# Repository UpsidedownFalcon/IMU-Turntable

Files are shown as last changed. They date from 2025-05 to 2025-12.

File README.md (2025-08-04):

# High-Tech Fidget Spinner: 3-Axis IMU Turntable 

Welcome! 

This is an open-source project for the construction of a 3-DoF IMU turntable, called the "High-Tech Fidget Spinner". It is a low-cost alternative to commercial solutions which can cost in the 5 to 6-figure USD range, to be used for the validation and characterisation of IMU sensors. 

015_Tease2

System Architecture

The repository contains supporting files to the conference paper titled "High-Tech Fidget Spinner: Open-Source 3-Axis Turntable" from UbiComp Companion ’25, October 12–16, 2025, Espoo, Finland: https://doi.org/10.1145/3714394.3756256 

The top-level strucutre of the repository is as follows: 

```
.
├── build/              # 3D-printing files, instructions and BoM to construct the hardware    
├── docs/               # Project development and conference paper documentation 
├── src/                # Code for the webapp and controller firmware    
├── testing/            # Files from testing the High-Tech Fidget Spinner 
├── tools/              # Files to select approrpriate stepper motors 
├── LICENSE.md         
└── README.md           
```

Each directory has its own README file that contains further details about it. 

## Getting started 

0) Familiarise yoursel with the directories in this repository and their README files and the overview paper at https://doi.org/10.1145/3714394.3756256  

1) Construct the hardware as described in [```/build/```](/build/) 

2) Upload the firmware as described in [```/src/```](/src/)

3) Launch the webapp as described in [```/src/```](/src/) 

4) You're ready to use the project! Usage instructions can be found at [```/docs/how-to-use.md```](/docs/how-to-use.md) 

5) Modify as you need for your applications :) 

## Next steps 

The High-Tech Fidget Spinner is a **WORK IN PROGRESS** as of August 3, 2025. The community should follows this repository for the latest iterations. 

- A **FORK** of this repository should be created to modify the project for your bespoke applicaiton. 

- An **ISSUE** should be created to suggest changes / bug fixes for the entire community. 

Everyone is welcome to use, collaborate and iterate on this project!

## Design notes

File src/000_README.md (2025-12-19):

# ```/src/``` 

This directory is where all of the code is found! There is a webapp UI where the user can create bespoke trajectories and save them onto a MicroSD card. Then the MicroSD card can be inserted into the Teensy 4.1-based controller board for the High-Tech Fidget Spinner to execute the bespoke trajectories. This directory contains the code for the Teensy 4.1-based controller board and the webapp. 

```
├── firmware/          # Code for the controller board 
├── webapp /           # Code for the web-based UI
└── README.md 
``` 

## ```/src/firmware/``` 
- [```./main/main.ino```](/src/firmware/main/main.ino) is the code that should be flashed onto the controller board 
- [```./test-scripts/```](/src/firmware/test-scripts/) contains test code snippets 

## ```/src/webapp/``` 
- [```./static/```](/src/webapp/static/) contains CSS and JS files for the webapp 
- [```./templates/index.html```](/src/webapp/templates/index.html) is the HTML file for the webapp 
- [```./webapp.py```](/src/webapp/webapp.py) is the Python backend for the web UI 

## Using the code 

[```/src/firmware/main/main.ino```](/src/firmware/main/main.ino) can be uploaded to the Teensy 4.1 using the Arduino IDE by following the guide on https://www.pjrc.com/teensy/tutorial.html. 

You should run [```/src/webapp/webapp.py```](/src/webapp/webapp.py) to launch the webapp! ```pip install``` can be used to install any libraries that you don't have.

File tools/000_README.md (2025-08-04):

# ```/tools/``` 

There is a large variety of different stepper motors with different operating parameters. An appropriate combination of stepper motors must be chosen, because for example, the base stepper motor will experience the greatest load. This directory contains a model to output appropriate stepper motor combination from the inertia modelling in [/docs/development-log/PRD.md](/docs/development-log/PRD.md).  

```
├── /stepper-selection-model/
|   ├── stepper_data.csv                    # Different stepper motors' operating data 
|   ├── stepper_options.csv                 # Model output containing feasible stepper combinations 
|   └── stepper-selection-model.py          # Python model to choose approrpiate stepper motors 
└── README.md 
```

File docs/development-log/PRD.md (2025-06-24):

Product Requirements Document 
=============================

Contents
=========

1. [Rationale](#1-rationale)
2. [Design Brief](#2-design-brief)
3. [Existing Product Analysis](#3-existing-product-analysis) 
4. [Design Specification ](#4-initial-design-specification)
5. [Initial Design Ideas](#5-initial-design-ideas)
6. [Final Design](#6-final-design)
7. [Manufacturing](#7-manufacturing) 

## 1. Rationale 
Inertial Measurement Units (IMU sensors) widely used in wearable technologies. [Hippos Exoskeleton Incorporated](https://www.hippos.life/) are using IMU sensors in their world's first Smart Adaptive Knee Brace to prevent serious knee injuries such as ACL tears. 

In such applications, there is a demand for high frequency IMU measurements. It is also imperative to validate these high frequency IMU measurements to determine the accuracy of the IMU sensor. There is no consistent and economical method between different researchers to do so, hence why this project exists to fill that gap. 

Inertial Measurement Units (IMUs) are critical to wearable exoskeletons but lack a standardised, low-cost method to validate high-frequency data (500–1 000 Hz+) against a ground truth.

- **Problem statement:** Existing IMU validations rely on optical systems (≤240 Hz, ≈42% joint-angle error) or expensive commercial turntables, making cross-study comparison difficult.

- **Opportunity:** An open-source, 3-axis mechanical jig with rotary-encoder ground truth can deliver <9% error validation at high sampling rate

Please read *Research Proposal.pdf* for a detailed overview. 

## 2. Design Brief 
This project must produce an open-source and economical method to characterise and validate IMU sensor data against a ground truth, which can be applied across different researchers to consistently compare the accuracy of different IMU sensors at different sampling rates. 

The open-source hardware and software platform must:
1. Spin IMUs on a motorised 3 DOF jig at controlled trajectories. 
2. Log synchronous IMU and rotary-encoder data.
3. Compute and report accuracy metrics (RMSE, MAE, drift rates, Allan variance).
4. Be fully documented (CAD, firmware, analysis scripts) so that other labs can reproduce and compare results.

## 3. Existing Product Analysis
| Turntable | Rotation DoF | Rotation Range / ° | Rotation Resolution / ° | Linear DoF | Linear range | Linear Resolution | Cost / £ | Open-Source | Source Link |
|---|---:|---|---|---:|---|---|---|---|---|
| **iMAR iTES-PDT07** | 1 | Continuous (∞) | 0.00153 ° (5.5 arcsec) | 0 | N/A | N/A | On request | No | https://imar-navigation.de/en/product/ites-pdt07 |
| **iMAR iTURN-2D1-HIL** | 2 | Continuous (∞) | 0.00000556 ° (0.02 arcsec) | 0 | N/A | N/A | On request | No | https://imar-navigation.de/en/product/iturn-2 |
| **iMAR iTURN-3S1** | 3 | Continuous (∞) | < 0.0002 ° | 0 | N/A | N/A | On request | No | https://imar-navigation.de/en/product/iturn-3s1 |
| **LIOCREBIF Single-Axis Rate & Position Turntable** | 1 | Continuous (∞) | 0.0001 ° | 0 | N/A | N/A | On request | No | https://www.liocrebif.com/single-axis-rate-and-position-turntable |
| **360° Electric Rotating Photography Turntable (B0756FVW78)** | 1 | Continuous (∞) | ≈ 1 ° (no encoder) | 0 | N/A | N/A | £21 | No | https://www.amazon.co.uk/dp/B0756FVW78 |
| **JAYEGT Motorized Rotating Display Stand, 7.87 in** | 1 | Continuous (∞) | ≈ 0.18 ° (stepper microsteps) | 0 | N/A | N/A | £22 | No | https://www.amazon.co.uk/dp/B07XYZ1234 (approx.) |
| **OpenBuilds Compact Rotary Axis (DIY)** | 1 | Continuous (∞) | 0.05625 ° (1.8°/step with 1/32 microstep) | 0 | N/A | N/A | £160 (~\$200*) | Yes | https://openbuilds.com/builds/compact-rotary-axis-laser-engraver.10204/ |

### Rotational Actuators 
<details> <summary> Expand </summary> 
There are three main types of rotational actuation methods: pneumatic, hydraulic and electric. Pneumatic systems require large volumes of compressed air and hydraulic systems require powerful pumps. Hence, they would not be suitable for such an open-source IMU turntable as pneumatic and hydraulic actuators are difficult and expensive to obtain and control. 

For electric actuation methods (motors), there are several different types: 
- DC Motors 
    - DC Shunt Motor 
    - Separately Excited DC Motor 
    - Series DC Motor 
    - PMDC Motor 
    - Compound Motor 
- AC Motors 
    - Induction Motor 
        - 1 Phase Induction Motor 
        - 3 Phase Induction Motor 
    - Synchronous Motor 
- Special Motors 
    - Stepper Motor 
    - Brushless Motor 
    - Universal Motor 
    - Hysterisis Motor 
    - Reluctance Motor 
    - Linear Motor 

Comparing all of the motors against the design brief and specification: 
| **Motor Type** | **Approx. Angular Resolution** | **Control Method** | **Ease of Open-Source Control** | **Accessibility (Motor & Controller)** | **Notes/Comments** |
|---|---|---|---|---|---|
| **DC Shunt Motor** | • No inherent positional resolution (continuous).<br>• With external encoder: resolution = encoder CPR (e.g. 1000–5000 pulses/rev → 0.36–0.072°). | • Voltage/PWM to armature; field winding current is separately regulated (constant–voltage).<br>• Closed-loop position/velocity requires a separate encoder + PID. | • Moderate: plenty of open-source H-bridge/PWM drivers (e.g. VNH2SP30, L298N), open-source PID libraries (Arduino, Python).<br>• But you must pair with an encoder board and write/modify control firmware. | • DC shunt motors (small-frame) are somewhat uncommon compared to PMDC. You’ll likely end up using a small PMDC + stiff field winding rather than commercial “shunt”-type anyway.<br>• Encoder modules (optical/Hall sensor) are off-the-shelf. | • Without an encoder, you have zero positional resolution—only speed control.<br>• With a good encoder and a well-tuned PID loop, you can get “encoder resolution” (e.g. a 2000 CPR encoder → 2000 steps/rev → 0.18° per step).<br>• But this adds mechanical coupling, cost, and closed-loop complexity. |
| **Separately Excited DC Motor**  | • Same as DC Shunt: continuous. With encoder only. | • Armature PWM/voltage + independent field current supply.<br>• Position/velocity control via separate encoder + PID. | • Moderate: open-source drivers for armature.<br>• You also need to drive field winding (often constant DC). For position, same as above (external encoder + PID). | • Rare to find small (<100 W) commercial “SEDC” motors cheaply.<br>• Encoders sold separately. | • Very similar trade-off as DC Shunt.<br>• Slightly more complex field supply but resolution still comes from encoder. |
| **Series DC Motor** | • Continuous unless you clamp/inject feedback via encoder. With encoder: same as above. | • Armature & field current in series → torque varies with load.<br>• Position/velocity control only via encoder + PID. | • Moderate-Low: series DCs are less common for precise control (more used for high-speed or heavy loads).<br>• Open-source PWM drivers exist, but closed-loop tuning is tricky. | • Series DCs are mostly used in industrial big-frame (e.g. traction).<br>• Not recommended for small precision tabletop setups. | • Not typically chosen for low-speed/high-precision tasks because torque changes nonlinearly with load.<br>• Encoder required for any positional control → same complexity as PMDC. |
| **PMDC Motor** | • Continuous rotation.<br>• With external encoder: depends on encoder (e.g. 1000 CPR yields 0.36°/step). | • PWM/analog voltage on armature.<br>• Closed-loop via encoder + PID. | • Moderate: a huge variety of open-source H-bridge drivers (e.g. L298, BTS7960, Pololu Motor Drivers) and PID libraries.<br>• You still need to attach an encoder (often 6–12 mm optical/line encoder modules). | • Very common: 12 V/24 V hobby-grade PMDC motors, cheap.<br>• Encoders widely available (e.g. 512–4096 CPR).<br>• Controllers: easy to source (Arduino shields, Pololu, etc.). | • Many DIY IMU turntables use a PMDC + high-resolution encoder.<br>• You’ll need to machine or 3D-print a coupling to mount the encoder disc.<br>• Control loop tuning (PID) is doable but adds software complexity vs. open-loop stepper. |
| **Compound Motor** | • Same as other DC: continuous. With encoder: same as above. | • Combination of series & shunt field windings; control as “DC motor + encoder.” | • Moderate: identical to DC motors above, but field structure is more complex. | • Rare—compound DC motors default to larger-frame/industrial sizes. | • Overkill for a small, low-power turntable.<br>• Complexity and cost go up for marginal gain over PMDC. |
| **1 Phase Induction Motor** | • No inherent positional resolution (just speed).<br>• Typically no encoder in standard usage. | • AC supply ± V/f control or VVVF (variable-voltage variable-frequency).<br>• For position: must retrofit encoder + VFD with encoder feedback (closed-loop). | • Low: open-source VFD+firmware exist (e.g. OpenVFD), but complex to set up.<br>• Tuning AC V/f control with encoder feedback is nontrivial. | • Small single-phase induction motors are common (ceiling fans, etc.) but rarely sold as “servo-ready.”<br>• VFDs with encoder inputs are industrial gear. | • Not practical for precision.<br>• Difficult to source a “small” 1 phase induction motor combined with a VFD that can do position-loop. |
| **3 Phase Induction Motor** | • Continuous; needs external encoder for any position control (like 1024 CPR → 0.35°). | • 3-phase inverter (VFD) → V/f open loop or vector control closed loop (with encoder). | • Low: projects like OpenInverter & ODrive support BLDC/AC motors, but setting up sensorless or encoder-based FOC for an IM is advanced.<br>• Requires a multi-kW inverter normally. | • Small 3-phase induction motors (e.g. 0.5–2 kW) are available but need a matching VFD.<br>• Commercial VFDs are expensive and not plug-and-play. | • Overkill power & complexity.<br>• Hard to find a compact open-source solution for 3 phase IM position control at tabletop scales. |
| **Synchronous Motor** | • Continuous; with resolver/encoder you get resolution = sensor CPR (e.g. 1024 CPR). | • Synchronous inverter drive (FOC) with encoder/resolver feedback.<br>• Position loop in the inverter. | • Medium-Low: some open-source ESC projects handle BLDC, but true AC synchronous (e.g. permanent magnet synchronous) with encoder is rarer.<br>• Requires writing/using FOC code. | • Small permanent-magnet synchronous motors (PMSM) exist (same as BLDC stator).<br>• Controllers: ODrive or similar can drive PMSM, but hardware is more expensive than stepper drivers. | • If you treat a PMSM like a BLDC (just use FOC + encoder), resolution is same story as BLDC.<br>• More complexity than a stepper for similar closed-loop accuracy. |
| **Stepper Motor** | • Native step angle: typically 1.8° (200 steps/rev) or 0.9° (400 steps/rev).<br>• Microstepping → up to 1/256 microstep. | • Open-loop step pulses (e.g. STEP/DIR) to driver (A4988, DRV8825, TMC²X).<br>• Closed-loop (optional) with encoder but often not needed if torque is adequate. | • Very High: virtually all major open-source platforms (Arduino, Raspberry Pi, etc.) have libraries for step/direction.<br>• Numerous open hardware drivers (e.g. BigTreeTech, CNC shield, TMC drivers). | • Ubiquitous: NEMA 17, NEMA 23 stepper motors are cheap.<br>• Drivers like A4988 (<\$2) or TMC2209 (<\$10) are open source/hardware friendly. | • Industry standard for DIY turntables, 3D printers, CNC.<br>• No encoder needed unless you want absolute position, since open-loop step is predictable.<br>• If you microstep and drive smoothly, you can achieve <0.05° resolution easily.<br>• Torque tapers at very high microstep frequencies—choose a low RPM application. |
| **Brushless Motor** (BLDC/PMSM) | • No inherent position resolution; requires external encoder/ITR.<br>• With 500 CPR encoder on rotor: 0.72° per count, but FOC interpolation can give ~0.1°. | • 3-phase ESC or driver (with FOC).<br>• With encoder or Hall sensors → closed-loop position.<br>• Without sensor → sensorless control (not recommended for precise stepping). | • Medium: boards like ODrive (open-hardware) or SimpleFOC (STM32) let you do FOC + encoder.<br>• More firmware overhead than a stepper. | • Brushless hobby motors are cheap; need to add a 3-phase inverter board + encoder.<br>• ODrive boards start at ~$100; SimpleFOC shields exist. | • Smooth motion and high-speed capability.<br>• More complex wiring (3 phases + encoder).<br>• Open-source BLDC drivers exist but require learning FOC concepts.<br>• You can tune so that effectively you get sub-degree control, but it’s not as “plug & play” as a stepper. |
| **Universal Motor** | • Continuous; requires an encoder for position resolution only. | • Runs off AC or DC (brush + commutator).<br>• Speed roughly ∝ voltage/load.<br>• Position control → PWM + encoder + PID. | • Low: open-source H-bridge PWM control can run it on DC.<br>• But brushes introduce noise; closed-loop tuning is not common. | • Found in power tools/household; not generally sold by RPM characteristics.<br>• Encoder + coupling required. | • Not used for precision positioning; mostly high-speed tools.<br>• Brush noise, variable torque curve. |
| **Hysteresis Motor** | • Often used in analog timing; continuous.<br>• No built-in position feedback.<br>• With external encoder: same as DC. | • AC drive at rated frequency; torque due to hysteresis; constant speed so good for timers.<br>• Position control only via external encoder + special driver. | • Very Low: rare to find open hardware for hysteresis motor control.<br>• Most commercial units come as “black box” synchronous timers. | • Extremely niche; mostly in lab instrumentation (analytical balances, audio turntables decades ago). | • Very expensive, low-torque.<br>• Rarely sold off-the-shelf for DIY. |
| **Reluctance Motor** | • Continuous.<br>• Position control requires resolver or encoder. | • 3-phase inverter (FOC or reluctance-specific drive).<br>• Position loop in inverter if encoder/resolver present. | • Low: open-source FOC for reluctance motors is uncommon.<br>• You’d basically need a commercial servo drive. | • Rarely sold at small scales.<br>• More used industrially (traction, servo); not easy to source cheap. | • Not a practical choice unless you already have one. |
| **Linear Motor** (not rotary) | • N/A for angular application. | • Typically voice-coil style (for small); linear brushless for larger. | • Low: open-source happens mainly in pick-and-place robotics, but not relevant for a rotary turntable. | • Widely available as linear actuators but useless for rotation. | • You’d have to convert linear → rotary (belt or gear) which adds inaccuracy. |

The most feasible motors to use are **stepper motors** because they: 
- Can rotate to discrete positions which can be sequentially combined to make them follow continuous rotation trajectories very accurately 
- Have a native angular resolution of 1.8° or 0.9° which can be microstepped up to 1/256 => Hence, a maximum achieveable resolution (with 0.9° native resolutio and 1/256 microstep) is **0.0035°** per microstep 

Using stepper motors, an open-source IMU turntable can be designed in [Initial Design Ideas: Stepper Motor Design](#stepper-motor-design). 
</details>

### Specific Stepper Motors 
<details> <summary> Expand </summary>

| Model | NEMA Size | Step Angle (°) | Holding Torque (N·cm) | Dimensions (mm) | Mass (kg) | Rotor Intertia (gcm2) | Datasheet Link |
|---|---|---|---|---|---|---|---|
| **14HR05-0504S** | NEMA 14 (Φ36.5) | 0.9 | 5 | Φ36.5 × 12.5; shaft Φ5×10.5 | 0.06 | 11.00 | [14HR05-0504S.pdf](https://www.oyostepper.com/images/upload/File/14HR05-0504S.pdf) |
| **14HR08-0654S** | NEMA 14 (Φ36) | 0.9 | 8 | Φ36 × 20; shaft Φ5×15.5 | 0.13 | 13.00 | [14HR08-0654S.pdf](https://www.oyostepper.com/images/upload/File/14HR08-0654S.pdf) |
| **14HM08-0504S** | NEMA 14 (35×35) | 0.9 | 5 | 35 × 35 × 20 | ~0.10 | 8.00 | [14HM08-0504S.pdf](https://www.omc-stepperonline.com/download/14HM08-0504S.pdf) |
| **14HM11-0404S** | NEMA 14 (35×35) | 0.9 | 11 | 35 × 35 × 11.5 | 0.12 | 10.00| [14HM11-0404S.pdf](https://www.oyostepper.com/images/upload/File/14HM11-0404S.pdf) |
| **16HM09-1204S** | NEMA 16 (Φ39) | 0.9 | 11 | Φ39 × 24 | 0.10 | 10.00 | [16HM09-1204S.pdf](https://www.omc-stepperonline.com/download/16HM09-1204S.pdf) |
| **16HM10-0604S** | NEMA 16 (Φ39) | 0.9 | 16 | Φ39 × 24 | 0.12 | 11.00 | [16HM10-0604S.pdf](https://www.oyostepper.com/images/upload/File/16HM10-0604S.pdf) |
| **16HM13-0404S** | NEMA 16 (Φ39) | 0.9 | 18 | Φ39 × 28 | 0.18 | 20.00 | [16HM13-0404S.pdf](https://www.oyostepper.com/images/upload/File/16HM13-0404S.pdf) |
| **16HM17-0304S**| NEMA 16 (Φ39) | 0.9 | 25 | Φ39 × 34 | 0.25 | 36.00 | [16HM17-0304S.pdf](https://www.oyostepper.com/images/upload/File/CN-16HM17-0304S.pdf) |
| **17HM08-1204S** | NEMA 17 (42×42) | 0.9 | 11 | 42 × 42 × 20 | 0.15 | 14.00 | [17HM08-1204S.pdf](https://www.oyostepper.com/images/upload/File/17HM08-1204S.pdf) |
| **17HM13-0316D** | NEMA 17 (42×42) | 0.9 | 23 | 42 × 42 × 34 | 0.28 | 38.00 | [17HM13-0316D.pdf](https://www.oyostepper.com/images/upload/File/17HM13-0316D.pdf) |
| **17HM13-0316S** | NEMA 17 (42×42) | 0.9 | 23 | 42 × 42 × 34 | 0.28 | 38.00 | [17HM13-0316S.pdf](https://www.oyostepper.com/images/upload/File/17HM13-0316S.pdf) |
| **17HM15-0406S** | NEMA 17 (42×42) | 0.9 | 26 | 42 × 42 × 39 | 0.28 | 54.00 | [17HM15-0406S.pdf](https://www.oyostepper.com/images/upload/File/17HM15-0406S.pdf) |
| **17HM15-0904S** | NEMA 17 (42×42) | 0.9 | 36 | 42 × 42 × 40 | 0.28 | 54.00 | [17HM15-0904S.pdf](https://www.oyostepper.com/images/upload/File/17HM15-0904S.pdf) |
| **17HM15-1004S** | NEMA 17 (42×42) | 0.9 | 33 | 42 × 42 × 40 | 0.31 | 54.00 | [17HM15-1004S.pdf](https://www.oyostepper.com/images/upload/File/17HM15-1004S.pdf) |
| **17ME15-1504S** | NEMA 17 (42×42) | 0.9 | 30 | 42 × 42 × 38 | 0.28 | - | [17ME15-1504S.pdf](https://www.oyostepper.com/images/upload/File/17ME15-1504S.pdf) |
| **17HM19-0406D** | NEMA 17 (42×42) | 0.9 | 32 | 42 × 42 × 48 | 0.35 | 68.00 | [17HM19-0406D.pdf](https://www.oyostepper.com/images/upload/File/17HM19-0406D.pdf) |
| **17HM19-1684S** | NEMA 17 (42×42) | 0.9 | 44 | 42 × 42 × 47 | 0.35 | 68.00 | [17HM19-1684S.pdf](https://www.oyostepper.com/images/upload/File/17HM19-1684S.pdf) |
| **17HM19-1684D** | NEMA 17 (42×42) | 0.9 | 44 | 42 × 42 × 48 | 0.35 | 68.00 | [17HM19-1684D.pdf](https://www.oyostepper.com/images/upload/File/17HM19-1684D.pdf) |
| **17HM19-2004S** | NEMA 17 (42×42) | 0.9 | 46 | 42 × 42 × 48 | 0.40 | 82.00 | [17HM19-2004S.pdf](https://www.oyostepper.com/images/upload/File/17HM19-2004S.pdf) |
| **17HM19-2004S1**  | NEMA 17 (42×42) | 0.9 | 46 | 42 × 42 × 48 | 0.37 | 68.00 | [17HM19-2004S1.pdf](https://www.oyostepper.com/images/upload/File/17HM19-2004S1.pdf) |
| **23HM22-2804S** | NEMA 23 (57×57) | 0.9 | 115 | 57 × 57 × 56 | 0.70 | 300.00 | [23HM22-2804S.pdf](https://www.oyostepper.com/images/upload/File/23HM22-2804S.pdf) |

Using this data, appropriate stepper motors can be selected for each axis of rotation, shown in [Final Design: Stepper Motor Selection Calculations](#stepper-motor-selection-calculations).

</details>

## 4. Design Specification  
The open-source IMU turntable must: 
1. 3 degrees of rotational freedom 
2. 360° of rotation about all three axes 
3. Rotational resolution of at least 0.05625°
4. **As cheap as possible** 
5. Variable trajectory control of the turntable 
6. IMU sensor datalogging at variable frequencies 
7. Temporal synchronisation of the IMU data and turntable motion 

## 5. Initial Design Ideas 
From *Research Proposal.pdf*, the following selections have been made: 

### IMU Sensors: 
The following IMU sensors were selected due to their variety in sampling frequency specified on their datasheet and due to the support of SPI. 

**SPI will be used** to transfer IMU data to the datalogger as it is the fastest digital communication protocol between I2C and UART. 

| IMU Sensor | Communication Protocol | Sampling Frequency / Hz | Angular Resolution / ° s^{-1} | Bit Depth |
|---|---|---|---|---|
| Analog Devices ADIS16470 | SPI | 5000 | ±2000 | 16 - 32 bit | 
| InvenSense ICM-20602 | SPI and I2C | 1 - 32000 | ±2000 | 16 bit | 
| Bosch BMI088 | SPI and I2C | 2000 | ±2000 | 16 bit |
| Ceva BNO085 | SPI, I2C and UART | 1000 | ±2000 | 16 bit |

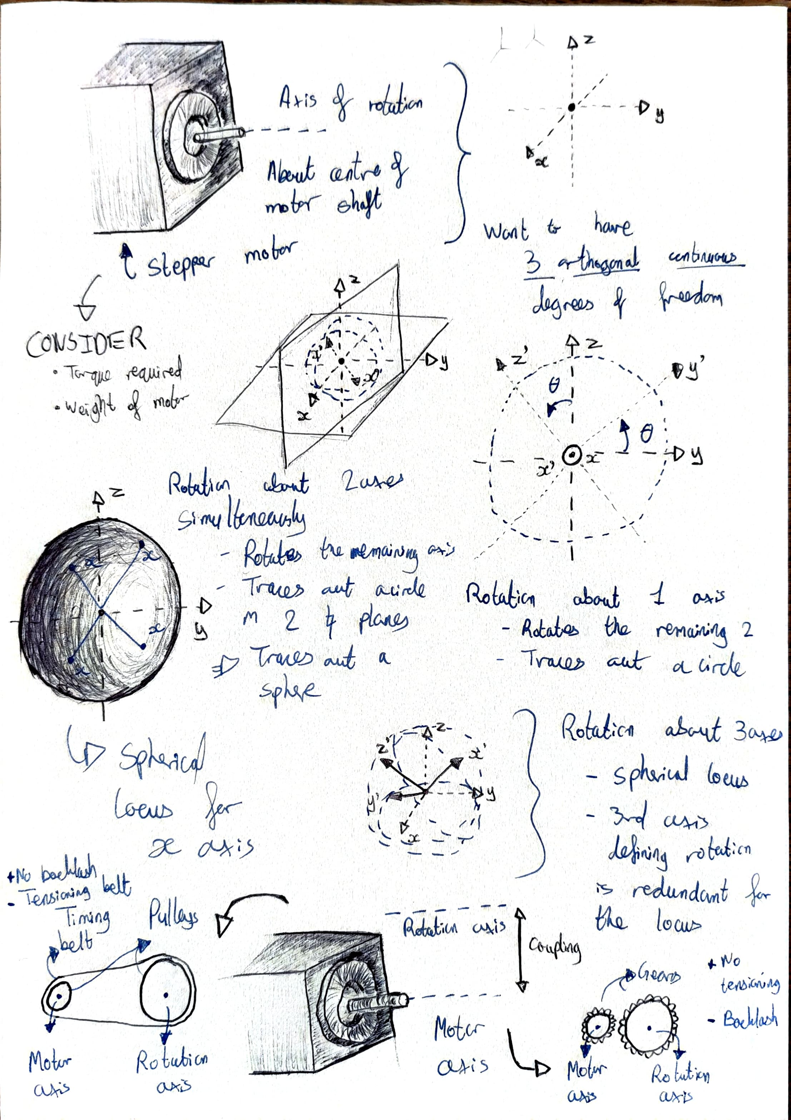
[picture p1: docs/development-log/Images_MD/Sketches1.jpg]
Initial Sketch 1
 
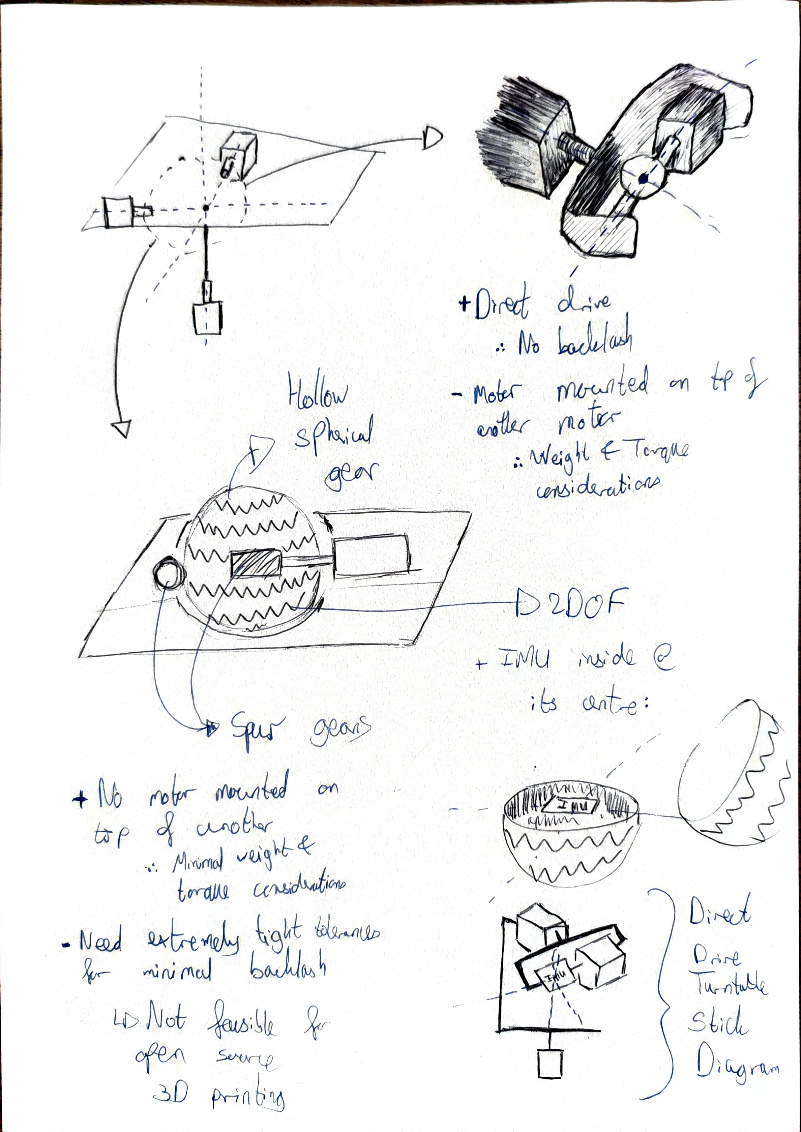
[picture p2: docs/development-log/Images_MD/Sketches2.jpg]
Initial Sketch 2


From the initial design ideas, a direct drive system is the most feasible because *accuracy and precision* are a priority, so **zero backlash** is a necessity. With such a system, the maximum attainable resolution must be further investigated by researching existing rotational actuators e.g stepper motors in [Existing Product Analysis: Rotational Actuators](#rotational-actuators). 

### Stepper Motor Design
<details> <summary> Expand </summary>
Initial design sketch of an open-source IMU turntable actuated using stepper motors: 

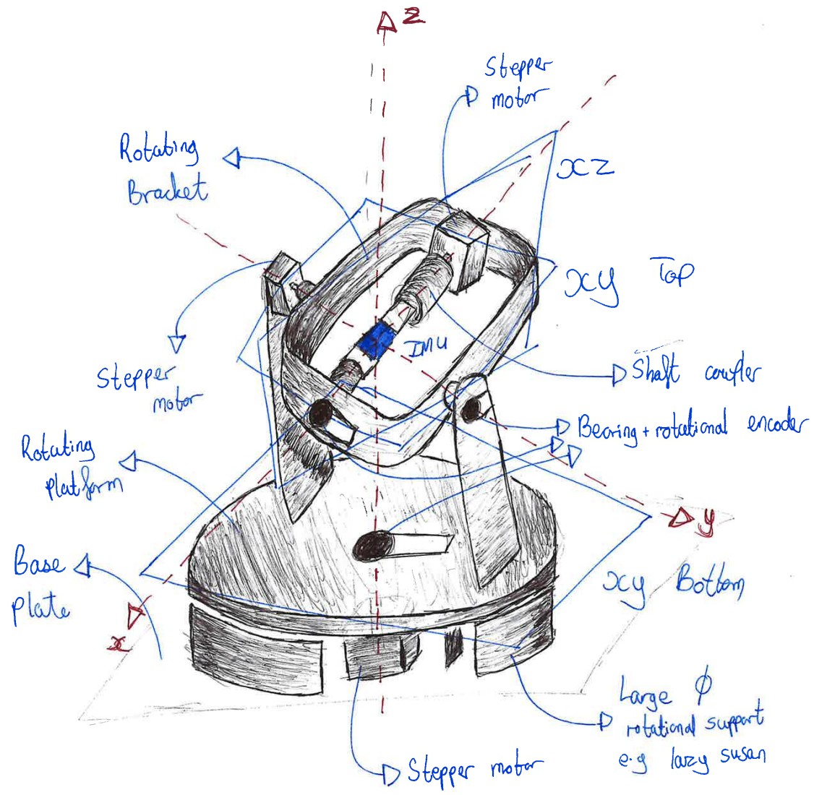
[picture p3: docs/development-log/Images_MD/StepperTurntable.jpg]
Initial Stepper Sketch
 
The drawback with using such a direct drive system is that the stepper motor at the base will have a greater load than the stepper motor at the top because the mass of the turntable + IMU > mass of IMU. **Next step** is to figure out which specific stepper motors to use - for that: 
- Need to research which specific stepper motors there are in [Existing Product Analysis: Specific Stepper Motors](#specific-stepper-motors) and their corresponding torques, dimensions and mass 
- Need to determine which combination of stepper motors to use and where, shown in [Final Design: Stepper Motor Selection Calculations](#stepper-motor-selection-calculations)
</details>

## 6. Final Design 

### Stepper Motor Selection Calculations
<details> <summary> Expand </summary>

- The [Firepower 2TS-450](https://www.accelerometergyro.com/sale-30377756-remote-control-position-rate-turntable-for-ins-imu-test-and-calibration.html) has a maximum angular acceleration of 300 °s^{-2} = **5.236 rads^{-2}**
- **Motor Torque = Load Torque + Friction Torque**, where **Torque = Inertia x Angular Acceleration** 
    - For load torque, **load inertia** depends on the mass and size of the IMU and the frame it's attached to 
    - Friction torque can be modelled as the torque required to spin ANOTHER motor shaft. That's because a bearing + rotary encoder would be used on the other side of the rotating axis. Specific components for the bearing + rotary encoder are yet to be selected, so by modelling them as ANOTHER motor shaft, it gives an OVERESTIMATE to the torque required from the motor. 
- The IMU sensor can be modelled as a solid rod of uniform density by using the maximum mass and dimensions from the list of IMU sensors in the [Initial Design Ideas](#5-initial-design-ideas): 
    - Maximum mass: **11.86g** of the ADIS16470 
    - Maximum length: **15.25mm** of the ADIS16470 

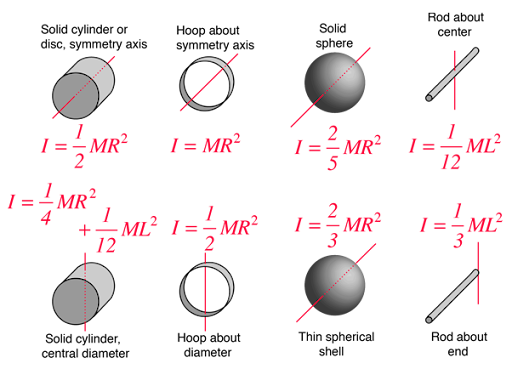
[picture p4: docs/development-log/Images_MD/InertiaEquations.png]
Inertia Equations
 

Hence, **I_IMU** = 1/2 x 11.86E-3 x (15.25E-3)^2 = **1.379E-6 kgm^2**

#### Stage X: Rotation about the X axis 
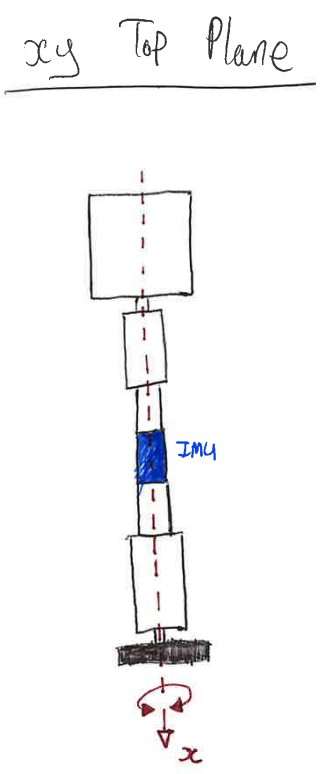
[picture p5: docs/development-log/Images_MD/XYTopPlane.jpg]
Stage X
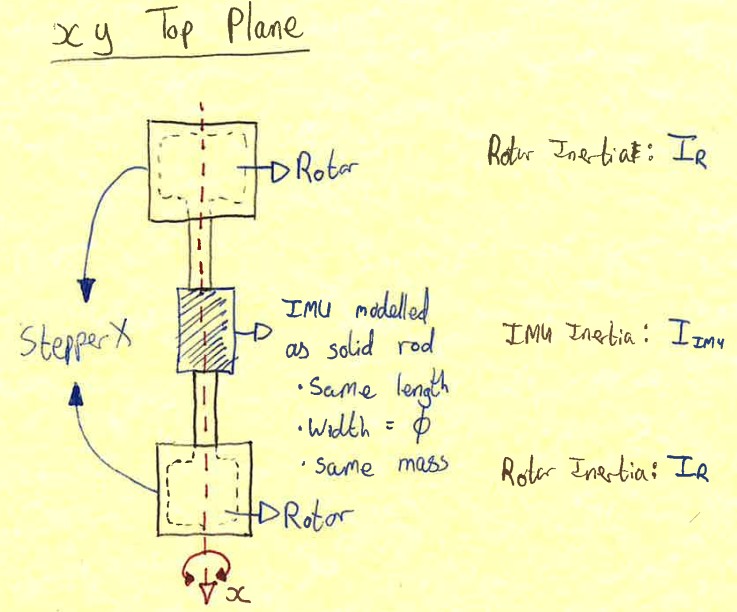
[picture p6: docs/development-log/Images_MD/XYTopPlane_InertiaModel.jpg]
Stage X Inertia Model
 =>  

Since a parts list hasn't been finalised yet, the following modelling assumptions are made to approximate the inertia: 
- Rotor inertia of the stepper motor causes a greater resistance to rotation than the friction in a ball bearing as the rotor has a greater mass than just a rotational axis. Hence, by modelling the resistance to motion due to a ball bearing as the inertia of a rotor will provide an overestimate. 
- Hence, total inertia the motor has to rotate = X Rotor Inertia (I_RX) + IMU Inertia (1.379E-6) + X Rotor Inertia (I_RX)

**=> X Motor Torque = (2I_RX + 1.379E-6)kgm^2 (5.236)rads^{-2}**

#### Stage Y: Rotation about the Y axis 
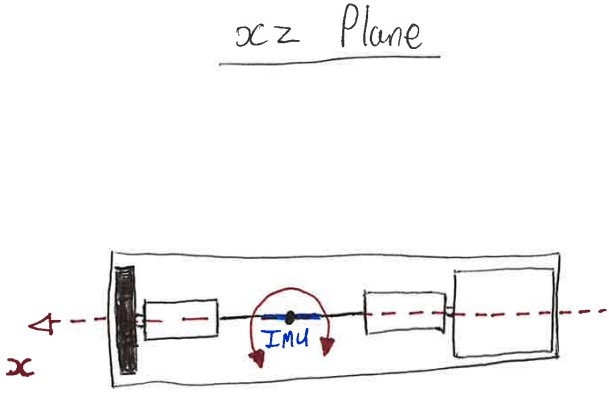
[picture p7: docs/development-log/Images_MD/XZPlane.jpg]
Stage Y
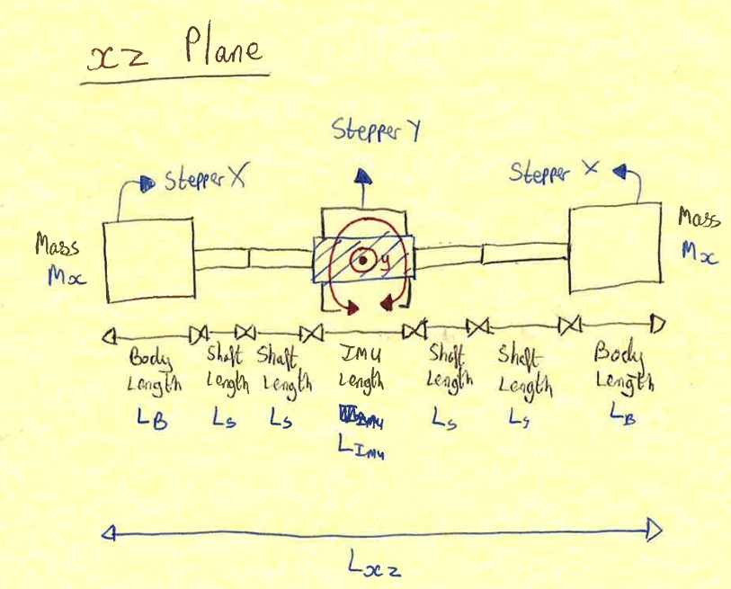
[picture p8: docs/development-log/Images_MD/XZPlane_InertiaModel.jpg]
Stage Y Inertia Model
 => 

Since a parts list hasn't been finalised yet, the following modelling assumptions are made to approximate the inertia: 
- Modelled as a solid rod rotating about its centre normal to its curved surface  
- Mass of rod approx. = (Mass of 2 X stepper motors) + IMU mass 
- Length of rod = 2LB_X + 4LS_X + L_IMU 
- Hence, total inertia by modelling the bearing support to have the same inertia as the Y motor = [1/12 x (2M_X + 11.86E-3) x (2LB_X + 4LS_X + 15.25E-3)^2] + 2 Rotor Inertia (2 I_RY) 

**=> Y Motor Torque = (1/12 (2M_X + 11.86E-3) (2LB_X + 4LS_X + 15.25E-3)^2 + 2 I_RY)kgm^2 (5.236)rads^{-2}**

#### Stage Z: Rotation about the Z axis 
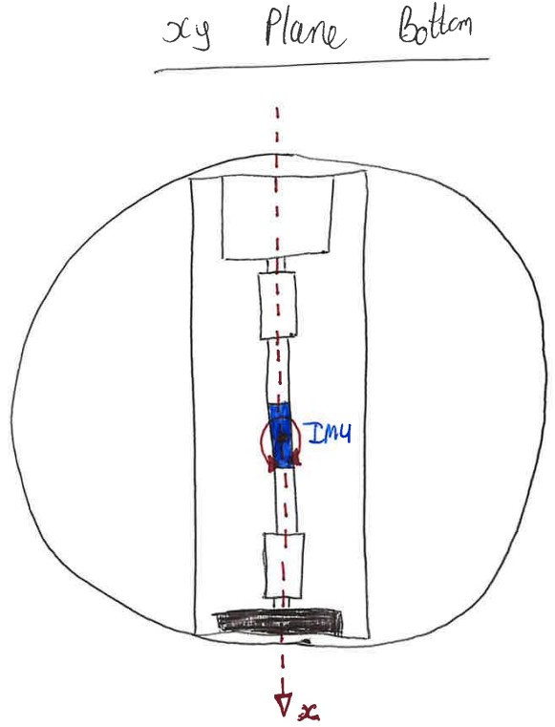
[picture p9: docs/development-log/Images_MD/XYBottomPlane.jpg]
Stage Z
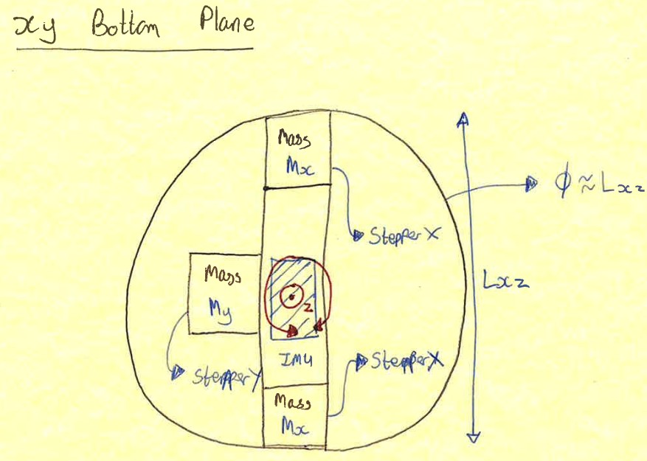
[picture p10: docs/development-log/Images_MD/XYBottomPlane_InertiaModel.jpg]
Stage Z Inertia Model
 => 

Since a parts list hasn't been finalised yet, the following modelling assumptions are made to approximate the inertia: 
- Modelling the rotating platform as an uniform-density rod rotating about its centre that is normal to its face 
- Mass of platform approx. = 2M_X + 2M_Y + M_IMU (assuming mass of Y axis support = M_Y)
- Radius of platform approx. = 1/2 L_XZ = 1/2 (2LB_X + 4LS_X + L_IMU) 
- Total inertia (assuming platform support has same inertia as Z Rotor Inertia) = 1/2 (2M_X + 2M_Y + 11.86E-3) (1/2 (2LB_X + 4LS_X + L_IMU))^2 + 2 I_RZ 

**=> Z Motor Torque = (1/8 (2 M_X + 2 M_Y + 11.86E-3) (2 LB_X + 4 LS_X + 15.25E-3)^2 + 2 I_RZ)kgm^2 (5.236)rads^{-2}**

#### Modelling Different Combinations of Stepper Motors 
As a safety factor, stepper motors will be selected with **at least 10x** the torque than the calculated required torque. 

The variables required are as follows: 
- I_RX: X Rotor Inertia in kgm^2 
- M_X: X Stepper Motor Mass in kg 
- LB_X: X Stepper Motor Body Length in m 
- LS_X: X Stepper Motor Shaft Length in m
- I_RY: Y Rotor Intertia in kgm^2 
- M_Y: Y Stepper Motor Mass in kg 
- I_RZ: Z Stepper Motor Rotor Inertia in kgm^2 

The constants used are as follows: 
- Maximum IMU Mass: 11.86E-3 kg
- Maximum IMU Length: 15.25E-3 m 
- Angular acceleration: 5.236 rads^{-2}

A [Python Script](Stepper_Selection_Model/Stepper_Selection_Model.py) was written to produce a list of [possible stepper motor combinations](Stepper_Selection_Model/stepper_options.csv). The following stepper motors are selected in row **1389**: 
- **X Axis Stepper Motor:** 14HM11-0404S 
- **Y Axis Stepper Motor:** 16HM17-0304S
- **Z Axis Stepper Motor:** 17HM19-2004S1
These motors can be purchased from [Stepper Online](https://www.omc-stepperonline.com/). 

Due to lead time of components from specialist electronic suppliers, the stepper motors were bought from Amazon instead. The desired models weren't available so the following were bought: 
- Nema 17 42-23 
- Nema 17 42-38 
- Nema 17 42-60 

[Rotary Encoder, Magnetic, Incremental, 4096 CPR, Straight](https://uk.farnell.com/broadcom/aeat-901b-r06/magnetic-encoder-incremental-straight/dp/4568216) were ordered due to lead time from Farnell. 

</details>

Largest IMU length was 33.25mm. Want to make an IMU mounting cradle where any IMU can be mounted and adjusted such that the IMU SoC is about the centre of the axes. Hence, cradle lengths should be double that @ ~70mm. 

## 7. Manufacturing

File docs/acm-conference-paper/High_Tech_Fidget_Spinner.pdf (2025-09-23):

# High-Tech Fidget Spinner: Open-Source 3-Axis Turntable

## Bhavy Vaibhav Metakar (https://orcid.org/0009-0001-6696-5230)

Hippos Exoskeleton Incorporated
London, United Kingdom
University College London
Electronic and Electrical Engineering London, United Kingdom
zceebme@ucl.ac.uk

## Thomas J. Gilbert (https://orcid.org/0000-0002-8846-8593)

University College London
Electronic and Electrical Engineering London, United Kingdom
thomas.j.gilbert@ucl.ac.uk

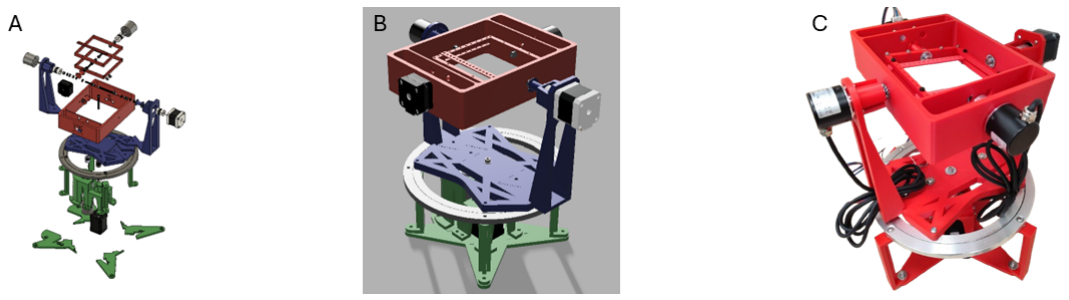
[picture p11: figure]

Figure 1: 3-DoF IMU-turntable exploded view (A), rendered model (B) and working prototype (C).

## Abstract

This paper presents an unprecedented fully open-source, 3-DoF turntable designed to enable precise characterisation and validation of inertial measurement units (IMUs), for under £500, which is a fraction of the cost of commercial systems. This design combines 3D-printed mechanical parts, off-the-shelf 3D printer electronics, and custom firmware with a web-based trajectory generator. Users define piecewise motion profiles for roll, pitch, and yaw via a cross-platform GUI; trajectories are saved to microSD and executed on a Teensy 4.1-based controller. The system can achieve a mean deviation as small as 0.0277◦ with a resolution of up to 0.0457◦
, and can hold a wide range of different IMU devices within a 100 mm × 100 mm area using its universal mounting fixture. All CAD files (STL/3MF/Fusion 360), electronics schematics, firmware source code, and configuration tools are freely available under the GNU GPLv3 licence. This platform lowers the barrier to rigorous IMU testing for researchers, educators, and makers without six-figure budgets, which is the cost of commercial solutions.

## CCS Concepts

- Hardware → Semi-formal verification; PCB design and layout.

## Keywords

3D Design, Custom Firmware, IMU, Testing, CAD, PCB Design, web app UI, Open-Source, FAIR

This work is licensed under a Creative Commons Attribution-NonCommercial 4.0 International License. (https://creativecommons.org/licenses/by-nc/4.0)
UbiComp Companion ’25, Espoo, Finland
© 2025 Copyright held by the owner/author(s).
ACM ISBN 979-8-4007-1477-1/2025/10 https://doi.org/10.1145/3714394.3756256

ACM Reference Format:
Bhavy Vaibhav Metakar and Thomas J. Gilbert. 2025. High-Tech Fidget Spinner: Open-Source 3-Axis Turntable. In Companion of the 2025 ACM International Joint Conference on Pervasive and Ubiquitous Computing (Ubi-Comp Companion ’25), October 12–16, 2025, Espoo, Finland. ACM, New York, NY, USA, 7 pages. https://doi.org/10.1145/3714394.3756256

## 1 Introduction

Wearable motion tracking systems increasingly rely on inertial measurement units (IMU sensors) to capture biomechanical kinematics live in the field, outside of laboratory settings. As such, IMU sensors are described as a cost-effective alternative to laboratory gold standards [1]. The total addressable market (TAM) for wearables grew by 23.1% from 2020 to 2021, reaching $10.28 billion [21], with 84% of devices used for exploring upper extremity musculoskeletal conditions containing IMU sensors [34].
Conventional IMU validation against optical motion capture systems is prone to marker misalignment, frame rate limitations, and soft tissue artefact (STA) in biomechanical contexts [23], producing a reported error of up to ±42◦ using a VR-based system [33]. Mechanical rigs with rotary encoders (turntables) offer a more accurate ground truth with a relative error below 9% [19]. Such IMU turntables are commercially available, but they are costly in the 5 to 6-figure USD range with proprietary firmware as shown in Table 1. This causes inconsistent data comparisons across different studies, and high costs hinder reproducible research.

## 1.1 Contributions

To address the aforementioned challenges, this paper presents the “High-Tech Fidget Spinner" (the artefact). It is a fully documented, vendor-agnostic and low-cost open-source turntable for IMU characterisation and data validation. This project contributes:

UbiComp Companion ’25, October 12–16, 2025, Espoo, Finland | Bhavy Vaibhav Metakar and Thomas J. Gilbert
- Hardware and Mechanical Design: A modular 3-DoF gimbal, built from 3D-printed PLA and standard 3D printer parts,
that executes preset trajectories and universally mounts any IMU device within a 100 mm × 100 mm frame.
- Electronics and Control: A control system based on a Teensy 4.1 microcontroller with three TMC2209 drivers and rotary encoders to execute a preset trajectory and capture the ground truth.
- Firmware and Software: Custom C++ firmware reads binary trajectory files from a microSD card, and a Python web app enables intuitive generation of piecewise X/Y/Z profiles.
- Open Ecosystem: Full CAD files, BOM, schematics, source code, and documentation released under the GNU GPLv3 licence.
- Validated performance: Customisable and repeatable rotations about 3 axes with sub-degree precision.

## 2 Related Work

This section outlines existing commercial closed-source, open-source IMU validation turntables and open-source principles.

## 2.1 Commercial IMU Validation Rigs

Table 1 shows different DoF, resolution and sample rate specifications for commercial turntables; prices are usually omitted, though the 3LT400 and 1LT300 retail in the six-figure USD range. Except for the JAYEGT turntable, they offer at least ≈ 0.001◦
angular resolution and sampling rates from 100 Hz − 1000 Hz.
The JAYEGT turntable is a novelty item, often used for photography. It is not designed to calibrate IMU sensors. Although such a device has a minimal cost barrier, it is not suitable for IMU calibration; its resolution data and sample rate, amongst other things, are not available.

## 2.2 DIY and Academic IMU Validation Rigs

There are free plans available on the internet for DIY 1-DoF turntable builds [13, 25, 30], as well as the construction of a simple turntable from an academic project [32].
Some designs available online employ 3D-printed gear mechanisms [13, 25]. Such mechanisms are not suitable for a turntable designed to characterise and validate IMU data due to the non-zero backlash [7].
Other designs [30, 32] employ a direct connection between the rotational actuator shaft and turntable. Two rigidly-coupled rotating shafts eliminate the issue of backlash, but the designs omit rotary encoders for IMU ground truth measurement.

## 2.3 Open-Source Hardware in Wearables

Open-source hardware should be findable, accessible, interoperable and reproducible [2]. With commercial solutions, they are findable but not accessible due to their cost, not interoperable due to their proprietary firmware and not reproducible due to companies’ intellectual property rights. DIY solutions are often findable, accessible, interoperable with modifications and reproducible, but they are not fit for IMU characterisation and validation.

Table 1: Comparison of commercial IMU turntables

Model | Cost / USD | DoF | Resolution / ° | Sample Rate / Hz
Firepower Control 3LT400 [28] | 210, 000.00 | 3 | 0.000833 | 80

Firepower
Control
2TS-450 [5]
NA | 2 | 0.006 | 1000

Blue Equator
BE-INS2-
22D08 [10]
NA | 2 | 0.00139 | NA

Firepower
Control
1LT300 [29]
180, 000.00 | 1 | 0.0001 | 100

iMAR iTES-PDT07 [16]

NA | 1 | 0.00153 | NA

iMAR
iTURN-2D1-
HIL [15]
NA | 2 | 5.56 × 10⁻⁶ | 1000

iMAR
iTURN-3S1
[14]
NA | 3 | 0.0002 | 1000

JAYEGT
Motorized
Rotating Display Stand
[18]
41.90 | 1 | NA | NA

## 3 Artefact Overview

This section outlines the design goals for the artefact, the rationale for choosing them and a high-level overview of the system.

## 3.1 Design Goals

From studying the Related Work, the following design goals were chosen to fill in the gaps identified:

- 3-DoF to outperform some commercial options.
- Synchronous logging of IMU and ground truth data.
- Fully documented and low-cost to be FAIR-compliant [2].
- 360◦ of continuous rotation about all of its axes, to match commercial solutions in Table 1.
- A rotational resolution ≤ 0.05625◦
to surpass the maximum
resolution of another stepper-motor-based turntable [32].
- Bespoke user-defined trajectories for versatility.

## 3.2 System Architecture

A browser GUI (HTML/CSS/JS frontend, Python/Flask backend) lets users define bespoke piecewise motion profiles and stepper motor parameters. It discretises each axis’s trajectory into timed angle steps, saves them to a microSD card, and the Teensy 4.1 controller (with TMC2209 drivers) loads and executes them on the X, Y, and Z stepper motors. During operation, the controller logs the ground

High-Tech Fidget Spinner: Open-Source 3-Axis Turntable | UbiComp Companion ’25, October 12–16, 2025, Espoo, Finland

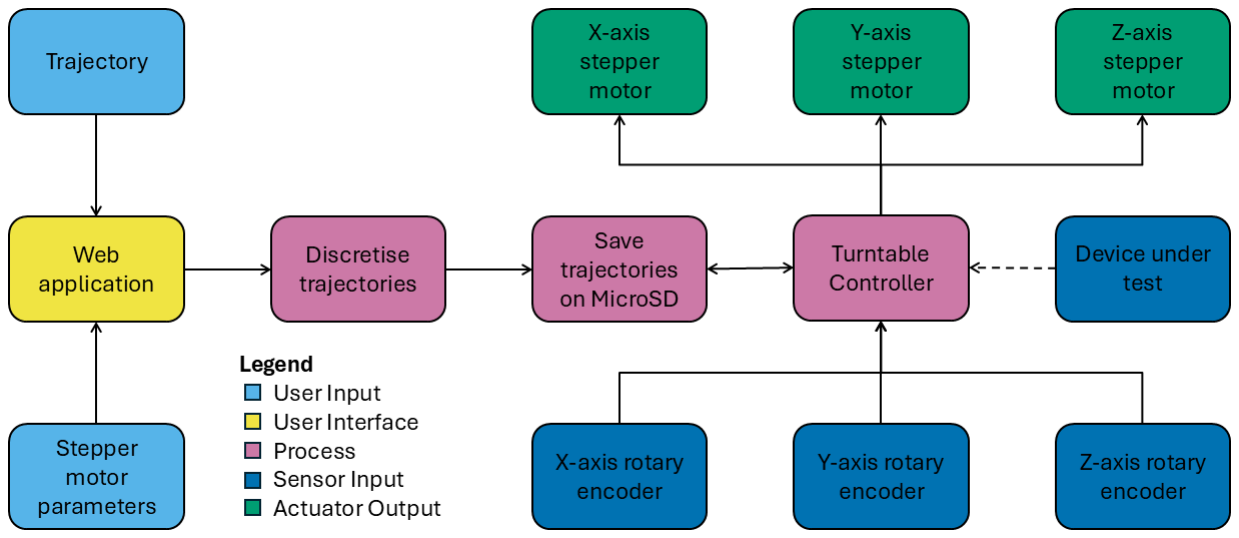
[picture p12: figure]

Figure 2: Browser GUI exports users’ trajectories as binary files to microSD, which the artefact executes.

truth via rotary encoders, and IMU data can stream over UART, I2C, or SPI, or be logged separately.

## 4 Mechanical Design

The artefact consists of a 3-DoF gimbal structure with motor and sensor mounts. The base rotates about the Z-axis. On top of the base, two orthogonal rotating gantries are mounted to rotate about the X and Y axes. A rigid shaft coupling was chosen between the stepper motors and rotating bodies over gearboxes or pulleys to eliminate backlash [7]. Various ball bearings support each frame, constrain a frame’s rotation to only its own axis and maintain orthogonal axes. All rotational frames and brackets were printed in PLA on a Bambulab X1E (0.2 mm layer height, 15 % infill), and the universal fixture clamps in 85A TPU on an Ender 5 (0.2 mm layer height, 20 % infill). Two different 3D printers were used to print the PLA and TPU parts in parallel, as printing in TPU requires a slower print speed and hotter nozzle temperature than PLA [3].
PLA offers higher stiffness (Young’s and bending moduli) and impact strength than ABS or PETG. PLA has minimal warp and does not need a heated bed or enclosure, unlike ABS or PETG [22]. Its low glass transition (≈ 60 ◦C [22]) limits use to below that temperature but ensures superior rigidity and dimensional stability in that range. PLA prints without enclosures or filtration systems, making it broadly accessible.

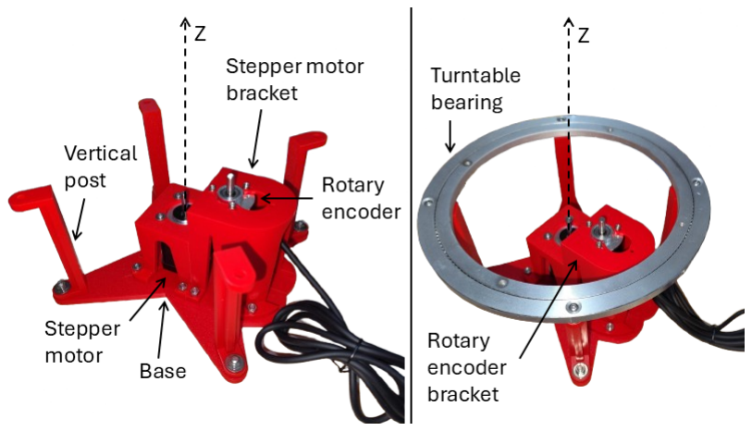
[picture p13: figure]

Figure 3: Base frame subassembly (left) for rotation about the Z-axis. A turntable bearing (right) adds stability to the subassemblies mounted on the base.

Figure 3 (left) shows the base subassembly with 4 vertical posts; a bracket for the base stepper motor; a bracket for the base rotary encoder, and a turntable bearing (right). The bearing mounts on top of the vertical posts to constrain undesired motion [11] for subassemblies on top of the base. The base stepper motor rotates the device under test (DUT) about the Z-axis, and the base rotary encoder measures the rotation about the Z-axis. The rotary encoder is connected to the stepper motor via a GT2 timing belt due to their minimal backlash, as the “backlash is distributed over a full half turn rather than happening immediately on direction change" [27]. Due to practical design considerations of a direct connection between the Z-axis rotary encoder and rotating subassemblies on top of the base, the rotary encoder was driven by a timing belt and pulley system rather than a direct-drive system.

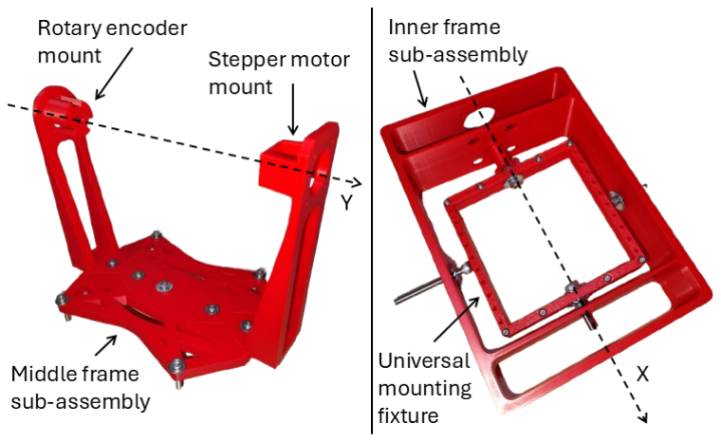
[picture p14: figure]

Figure 4: Middle frame subassembly (left) and inner frame subassembly (right) with rotational axes drawn.

Figure 4 (left) shows the middle subassembly with a mount to the turntable bearing on the base; a stepper motor mount, and a rotary encoder mount. It can be mounted to the turntable bearing on the base to ensure stable rotation in the X-Y plane, and a stepper motor and rotary encoder can be mounted along the Y-axis. This allows for rotation about the Y-axis and its measurement.
Figure 4 (right) shows the inner subassembly with a mount for the DUT; a stepper motor mount; a rotary encoder mount, and a mount to the middle assembly. The mount to the middle assembly is a pair of M5 machine screws which attach to the Y-axis stepper motor and rotary encoder through a set of bearings. The inner assembly can be connected to a stepper motor and rotary encoder to rotate the DUT about the X-axis and measure its rotation. The mount for the DUT forms part of the universal mounting fixture, with its other part being 3D-printed out of TPU.
Figure 1C shows the complete mechanical assembly of the artefact with a single point of rotation in the middle of the inner frame about three orthogonal axes. Its cost is under £500 (≈ $670).

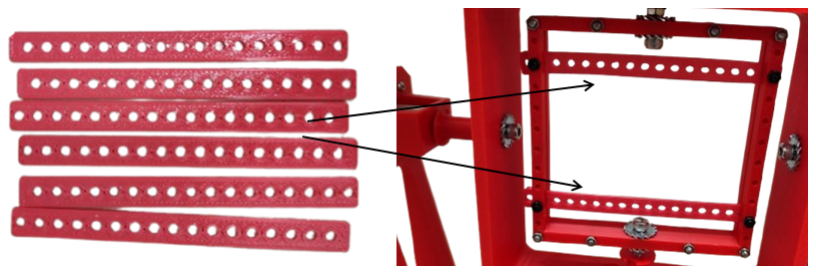
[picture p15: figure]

Figure 5: Universal mounting fixture made out of TPU (left) attached to the inner frame (right).

Figure 5 shows the second half of the universal mounting fixture which is 3D-printed out of TPU and attached to the inner frame.

The user can configure how many TPU mounts they need, where to place them and their tension using the holes in the TPU mount and the inner frame. The TPU mount is attached to the inner frame using M3 machine screws.

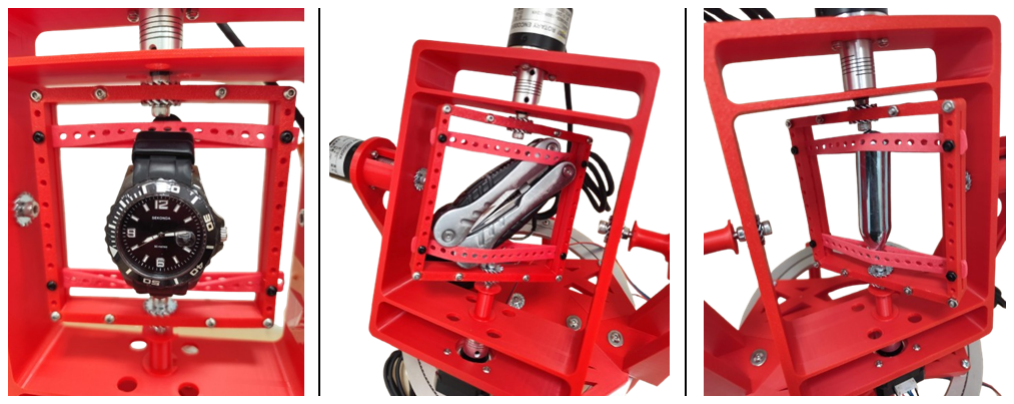
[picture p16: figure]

Figure 6: A watch (left), a multitool (middle) and a CO2 canister (right) secured using the universal mounting fixture.

Figure 6 shows the universal mounting fixture securely holding a watch, a multitool and a CO2 canister to demonstrate that it can hold a range of different objects, and hence, a range of IMU devices. The user has flexibility over where and how to place their object for their bespoke application.

## 5 Electronics and Firmware

This section describes the rationale behind the electronic components chosen, shows the schematic and gives an overview of the web app UI.

## 5.1 Stepper Motor Selection

5.1.1 Stepper Motors. To achieve 360◦

rotation and ≤ 0.05625◦
resolution on the 3-DoF IMU turntable, open-loop stepper motors were selected for their high native angular precision, simple control and availability [6]. Standard 1.8
- or 0.9

◦
stepper motors (200 or
400 steps per revolution), with up to 1 256 microstepping, provide a maximum of 0.0035◦
resolution per microstep [4]. Drivers that accept step and direction inputs obviate the complexity of feedback control required for DC or BLDC motors [31].

5.1.2 Dynamic Torque Modelling. Firepower Control’s 2TS-450 IMU turntable has an angular acceleration of 300 ◦
s

−2
[5]. To match
that lowest commercial angular acceleration from Table 1, each axis was modelled as a compound rigid body composed of cumulative frame, rotor and payload inertias. The model can be found in ./docs/development-log/PRD.md [26]:
- X-axis: τ = (2IRX + IIMU) · α
- Y-axis: τ =
1
12 (2MX + MIMU)L

2 + 2IRY
- α
- Z-axis: τ =
1
2

(2MX + 2MY + MIMU)R

2 + 2IRZ
- α

5.1.3 Selected Motors. A Python script in ./tools/stepper-selectionmodel/stepper-selection-model.py [26] was used to select appropriate stepper motors, filtering for those that meet the required torque, size, and inertia constraints with adequate margin and lead time:

- X-axis: Nema 17 42-23
- Y-axis: Nema 17 42-38
- Z-axis: Nema 17 42-60

5.1.4 Microcontroller, Drivers and Rotary Encoders. To maximise versatility, the controller is required to accommodate a user-supplied IMU and allow firmware extension to log data over any digital communication protocol. Commercial IMU turntables in Table 1 employ heterogeneous interfaces (such as CAN bus, which data loggers like laptops lack, and non-uniform USB ports/protocols), and data loggers support varied standards, including CAN bus, SDI-12, and MODBUS. Given the absence of a single, universal logging standard [12], reliance on any one would compromise interoperability; hence, the system must operate autonomously, necessitating onboard storage for recorded data.
Dynamic current control ensures smooth stepper motor performance under varying loads, and support for up to 256 microsteps maximises angular resolution and functional flexibility.
Optical rotary encoders were chosen over magnetic alternatives due to their superior accuracy and resolution [24].
The following components were chosen for the artefact’s controller due to their technical specification, cost and lead time:
- Microcontroller: Teensy 4.1 due to its 42 assignable GPIOs for UART, I2C and SPI, and a built-in microSD card slot [17].
- Stepper motor driver: TMC2209 due to its SpreadCycle chopper dynamic current control and 256 microstepping resolution [31].
- Rotary encoder: E38S6G5-600B-G24N optical rotary encoder, with 2400 quadrature pulses per revolution (PPR) [8].

## 5.2 Schematic

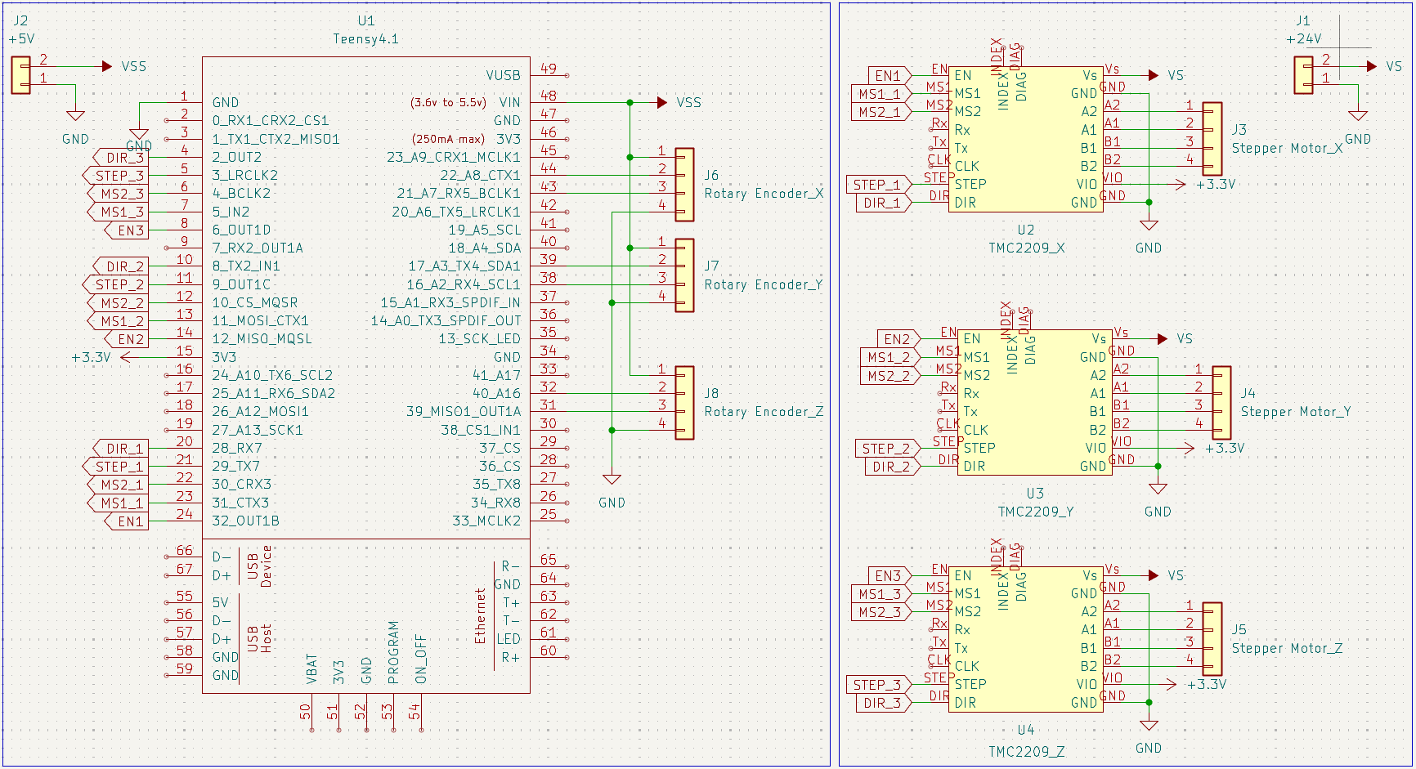
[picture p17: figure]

Figure 7: Schematic of the controller for the artefact.

Figure 7 shows the controller schematic consisting of a Teensy 4.1 microcontroller, three TMC2209 drivers, header pin connectors to the stepper motors and rotary encoders. It can be found in ./build/PCB/kicad [26] and can be constructed on a breadboard with an external power supply (≥ 120 W) for +24 V and +5 V. Files are also provided to manufacture a PCB.

## 5.3 Code Explanation

The web app GUI shown in Figure 8 allows the user to adjust stepper motor parameters; enter a piecewise trajectory for each axis; display the entered trajectory and discretise the trajectory to be saved onto a microSD card for execution by the artefact.

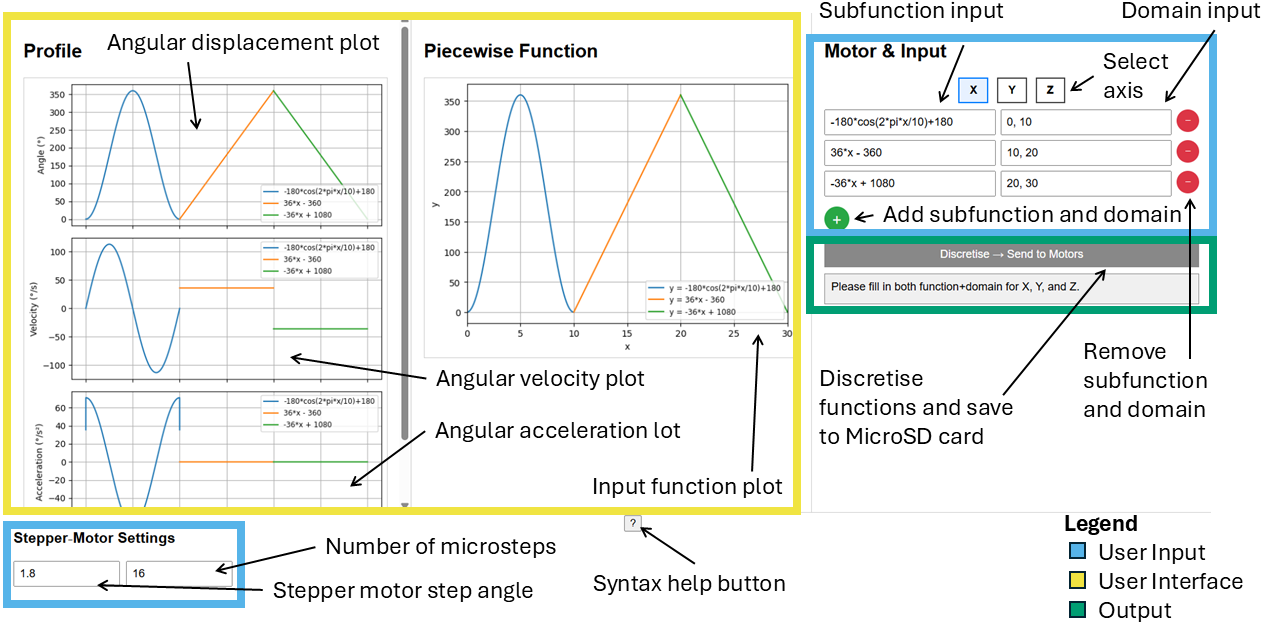
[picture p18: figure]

Figure 8: User interface with trajectory input fields (right), and visual trajectories (centre and left).

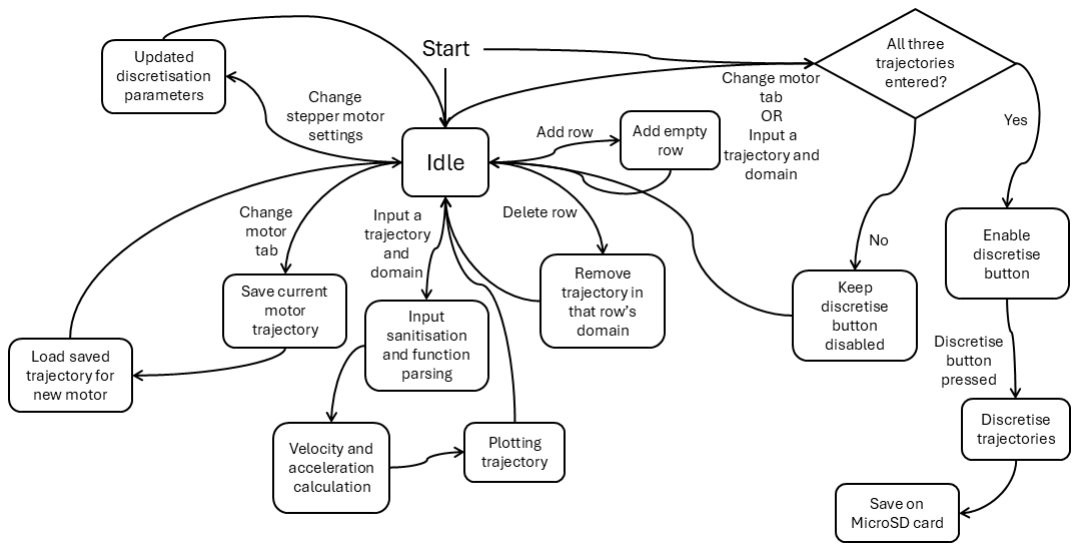
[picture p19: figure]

Figure 9: Web application interaction flow diagram.

Figure 9 shows the state transitions due to user inputs. The user can define bespoke trajectories as continuous piecewise functions. The mathematics used to discretise them into executable stepper motor trajectories is as follows:

5.3.1 User Input and Function Parsing. Each motor axis M ∈ {X, Y, Z} accepts a piecewise-defined angular trajectory as a set of symbolic functions fi(t) defined over domains [ai
, bi]:

fi(t) = sympify(user input), f num i
(t) = lambdify(fi(t), numpy)

5.3.2 Angular Resolution and Discretisation Step Size. The system computes the angular resolution per microstep:

θres =

θstep

μ
where θstep is the step angle (in degrees) and μ is the number of microsteps.
The angular trajectory is sampled at 1000 uniformly spaced time points; the maximum angular velocity is computed via first-order finite differences:

vmax = max

dθ

dt

≈ max
j

θ j+1 − θ j

tj+1 − tj

The discretisation time step dt is then computed as:

dt = max
θres

vmax

, dtmin

where dtmin is a fixed lower bound to prevent oversampling (e.g., dtmin = 0.002 s).

5.3.3 Sampling and Trajectory Construction. For each segment f

num
i

∈ [ai

, bi], we compute the number of samples:

Ni =

bi − ai

dt
+ 1

The time samples are then uniformly spaced:

tj ∈ linspace(ai
, bi

, Ni), θ j = f

num
| i

(tj)

The full trajectory is constructed by concatenating all segments while avoiding duplicate boundary points.

5.3.4 Velocity and Acceleration Profiling. Given the discretised angular positions θ j

, the velocity and acceleration profiles are computed numerically via finite differences:

ωj =

θ j+1 − θ j

dt

αj =

ωj+1 − ωj

dt
5.3.5 Validation and Export. The discretisation process is only enabled once valid input functions and domains are defined for all three axes X, Y, Z. Upon triggering, the discretised trajectories are stored as interleaved binary sequences on a microSD card:

[uint32 N] [float32 t0, θ0, t1, θ1, . . . , tN −1, θN −1]

## 6 Evaluation and Benchmarking

This section describes the benchmarking of the presented artefact.

## 6.1 Method

Infrared reflectors were placed on all rotating frames of the artefact. An Optitrak Prime X 22 motion capture system was used to capture its motion while performing a step trajectory from 0

◦

to 90◦
in
increments of 10◦
every 2 s. The stepper motor drivers on the artefact were configured to a standard 16-microstep configuration. The described procedure and its results are preliminary. The community can follow the project’s GitHub repository [26] for further and more thorough tests after design iterations.

## 6.2 Results

Figure 10 presents the motion capture measured angular displacement about the X (top), Y (middle), and Z (bottom) axes. Due to the motion-capture coordinate system definition, the measured trajectory rises from 0

◦

to 90◦

for the X and Z axes but falls to −90◦ for the Y-axis. Table 2 shows the mean deviation and resolution associated with the data in Figure 10, with the mean deviation and resolution increasing from the X to Z axes due to the greater mass rotating about it, hence, greater inertia and angular momentum. The maximum sample frequency from the rotary encoders is 100 kHz [8]. It is limited by the artefact’s angular velocity, as the output from the rotary encoders is a pulse and the pulse frequency, f = ω × PPR, where ω is the number of rotations per second and PPR is the number of pulses per revolution.

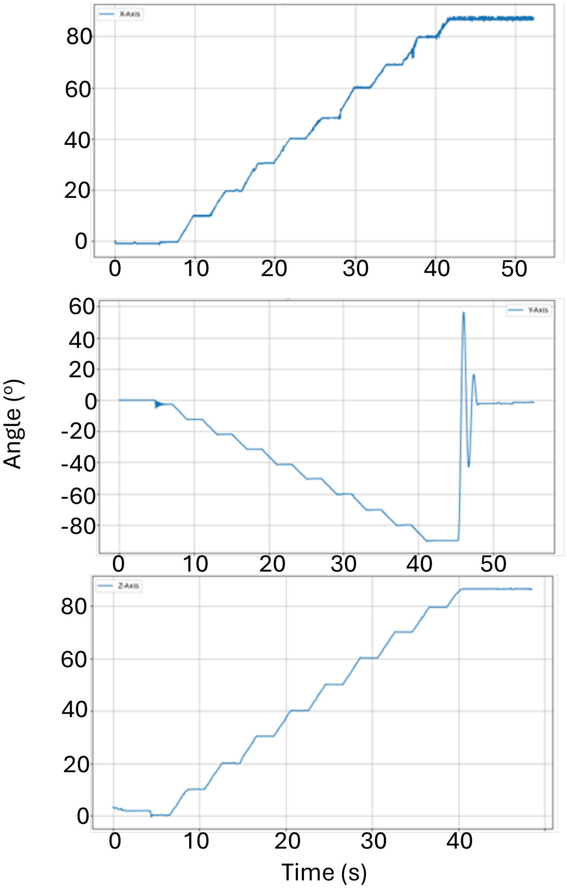
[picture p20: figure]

Figure 10: Euler angles of the X-axis (top), Y-axis (middle) and Z-axis (bottom) rotation.

Table 2: Error statistics of the artefact for rotation about each axis

| X-axis | Y-axis | Z-axis
Mean deviation / ° | 0.0277 | 0.0287 | 0.1758
σ (Mean deviation) / ° | 0.3266 | 0.8737 | 0.1603
Resolution / ° | 0.0461 | 0.0469 | 0.0457
σ (Resolution) / ° | 0.1142 | 0.0983 | 0.0586

## 6.3 Discussion

There were random errors present in the experiment, as the infrared reflectors were manually placed and stuck on using tape. Due to this, there are random errors in marker alignment and since the tape did not create a perfectly rigid joint, the markers underwent harmonic oscillations during acceleration, as shown by the data plotted in Figure 10.
The chosen trajectory was a step trajectory with a linear ramp between each step. This leads to a non-zero starting and ending velocity, and hence, the jolting motion. The largest ranges were observed during harmonic oscillation when the artefact first started moving upon being powered on. The jolting motion due to the trajectory, coupled with the stepper motors jumping to their nearest full steps, is likely the reason behind the largest ranges being one to two orders of magnitude larger than the smallest ranges.

## 6.4 Future Work

To address the issue of the jolting motion, it would be beneficial to explore how jerk-limited trajectories [20] can reduce the oscillatory motion of the artefact. A closed-loop control system for the stepper motors, such as PID control, remains to be explored for more accurate motions [9]. The maximum angular velocity and acceleration of the artefact have yet to be measured for different payload masses. To reduce random error from motion capture markers taped onto the artefact, the universal TPU mounting fixture can be used to mount the motion tracking markers. Configuring the stepper motor drivers to 256 microsteps would increase resolution.

## 7 Conclusion

As shown by Table 3, the presented artefact demonstrates that IMU characterisation need not be confined to six-figure instrumentation: the fully open-source, High-Tech Fidget Spinner delivers a minimum angular deviation of 0.0277◦

and a resolution of up to 0.0457◦ ,
costing under £500 (≈ $670), and built from readily available hardware and 3D-printed components. Compared to proprietary, closed commercial systems, it offers versatility and fidelity for a wide class of research, educational, and maker applications to increase access to validation of IMU sensors found in ubiquitous computing devices.
The artefact does not rival the ultimate resolution of commercial turntables, and its maximum velocity, acceleration and payloadcarrying capacities are unknown. Through community collaboration on the future work, the performance of this High-Tech Fidget Spinner can be further improved. By seeding the community with this accessible infrastructure, there is a possibility for broad adoption, iterative refinement, and novel applications in IMU verification.

Table 3: Comparison of the High-Tech Fidget Spinner to commercial IMU turntables

Turntable | Resolution / ° | DoF | Sample
Rate / Hz

Openness Cost / $

High-Tech
Fidget
Spinner
< 0.047 | 3 | < 100000 | Open | Under
| | | | 670.00

Firepower
Control
3LT400
[28]
0.000833 | 3 | 80 | Closed | 210, 000.00

Firepower
Control
1LT300
[29]
0.0001 | 1 | 100 | Closed | 180, 000.00

## 8 Code Availability

All of the code, supporting files and more details are available at https://github.com/UpsidedownFalcon/IMU-Turntable under the GNU GPLv3 licence [26].

## Acknowledgments

To Kylin and Ursula for their insightful feedback (and bagels). To Yung, Gerald and Andy for help with 3D printing parts. To Oli for giving feedback on UI design.

## References

[1] Jacob S Arlotti, William O Carroll, Youness Afifi, Purva Talegaonkar, Luciano Albuquerque, John E Ball, Harish Chander, Adam Petway, et al. 2022. Benefits of IMU-based wearables in sports medicine: Narrative review. International Journal of Kinesiology and Sports Science 10, 1 (2022), 36–43.
[2] Michelle Barker, Neil P Chue Hong, Daniel S Katz, Anna-Lena Lamprecht, Carlos Martinez-Ortiz, Fotis Psomopoulos, Jennifer Harrow, Leyla Jael Castro, Morane Gruenpeter, Paula Andrea Martinez, et al. 2022. Introducing the FAIR Principles for research software. Scientific Data 9, 1 (2022), 622.
[3] Emila Brancewicz-Steinmetz, Jacek Sawicki, and Paulina Byczkowska. 2021. The influence of 3D printing parameters on adhesion between polylactic acid (PLA) and thermoplastic polyurethane (TPU). Materials 14, 21 (2021), 6464.
[4] Tea Tran Cindy Chang. 2020. | Mastering Precision: Understand-
ing Microstepping in Motion Control. | Retrieved July 9, 2025 from
https://www.analog.com/en/resources/analog-dialogue/articles/masteringprecision-understanding-microstepping.html (https://www.analog.com/en/resources/analog-dialogue/articles/mastering-precision-understanding-microstepping.html)
[5] Firepower Control. 2025. | Remote Control Position Rate Turntable For
INS IMU Test And Calibration 2TS-450. | Retrieved July 9, 2025 from
https://www.accelerometergyro.com/sale-30377756-remote-control-positionrate-turntable-for-ins-imu-test-and-calibration.html (https://www.accelerometergyro.com/sale-30377756-remote-control-position-rate-turntable-for-ins-imu-test-and-calibration.html)
[6] Clarence W. de Silva. 2005. Mechatronics: An Integrated Approach. CRC Press, Boca Raton, FL, USA.
[7] Philipp Eisele, Sajid Nisar, and Franz Haas. 2024. A conceptual examination of an additive manufactured high-ratio coaxial gearbox. Artificial Life and Robotics 29, 3 (2024), 416–422.
[8] Sharvi Electronics. 2025. Datasheet E38S6G5 600B G24N. Retrieved July 9, 2025 from https://www.scribd.com/document/756625816/Datasheet-E38S6G5-600B-G24N (https://www.scribd.com/document/756625816/Datasheet-E38S6G5-600B-G24N)
[9] Nehal M Elsodany, Sohair F Rezeka, and Noman A Maharem. 2011. Adaptive PID control of a stepper motor driving a flexible rotor. Alexandria Engineering Journal 50, 2 (2011), 127–136.
[10] Blue Equator. 2021. High-Precision Automated Dual-Axis Positioning Turntable for INS & IMU Calibration. Retrieved July 9, 2025 from https://blueequatorai.com/products/high-precision-automated-dual-axis-positioning-turntablefor-optical-measurement,-aerospace,-and-robotics-calibration (https://blueequator-ai.com/products/high-precision-automated-dual-axis-positioning-turntable-for-optical-measurement,-aerospace,-and-robotics-calibration)
[11] Michael French. 1992. Form, Structure and Mechanism. Springer, New York, NY, USA.
[12] Sina Gholamian and Paul AS Ward. 2022. A Comprehensive Survey of Logging in Software: From Logging Statements Automation to Log Mining and Analysis. arXiv:2110.12489 (https://arxiv.org/abs/2110.12489) doi:10.48550/arXiv.2110.12489 (https://doi.org/10.48550/arXiv.2110.12489)
[13] Handy_Bear. 2022. How to Make a Motorized Lazy Susan With a Secret. Retrieved July 9, 2025 from https://www.instructables.com/How-to-Make-a-Motorized-Lazy-Susan-With-a-Secret/ (https://www.instructables.com/How-to-Make-a-Motorized-Lazy-Susan-With-a-Secret/)
[14] iMAR Navigation & Control. 2017. iMAR iTURN-3S1. Retrieved July 9, 2025 from https://www.imar-navigation.de/downloads/TURN-3S1.pdf
[15] iMAR Navigation & Control. 2024. iMAR iTURN-2D1-HIL. Retrieved July 9, 2025 from https://www.imar-navigation.de/downloads/TURN-2.pdf
[16] iMAR Navigation & Control. 2025. iTES-PDT-07. Retrieved July 9, 2025 from https://www.imar-navigation.de/downloads/TES_PDT07_turntable.pdf
[17] Adafruit Industries. n.d. PJRC Teensy 4.1 Development Board. Retrieved July 9, 2025 from https://mm.digikey.com/Volume0/opasdata/d220001/medias/docus/425/4622_Web.pdf (https://mm.digikey.com/Volume0/opasdata/d220001/medias/docus/425/4622_Web.pdf)
[18] JAYEGT. 2020. JAYEGT Motorized Rotating Display Stand, 7.87inch /17.6lbs Load, 360 Degree Electric Rotating Turntable for Photography Products, Jewelry, Cake,3D Model ,Mirror Cover (White). Retrieved July 9, 2025 from https://www.amazon.co.uk/JAYEGT-Motorized-Rotating-Turntable-Photography/dp/B08QS6YTHK (https://www.amazon.co.uk/JAYEGT-Motorized-Rotating-Turntable-Photography/dp/B08QS6YTHK)
[19] Hua-Kun Jia, Lian-Dong Yu, Hui-Ning Zhao, and Yi-Zhou Jiang. 2019. A new method of angle measurement error analysis of rotary encoders. Applied Sciences

9, 16 (2019), 3415.
[20] Hossein Barghi Jond, Vasif V Nabiyev, and Rifat Benveniste. 2016. Trajectory planning using high order polynomials under acceleration constraint. Journal of Optimization in Industrial Engineering 10, 21 (2016), 1–6.
[21] Min Jung Kang and Yong Cheol Hwang. 2022. Exploring the factors affecting the continued usage intention of IoT-based healthcare wearable devices using the TAM model. Sustainability 14, 19 (2022), 12492.
[22] Shayon Khaled. 2025. PLA vs ABS vs PETG: The Main Differences. Retrieved July 9, 2025 from https://all3dp.com/2/pla-vs-abs-vs-petg-differences-compared
[23] Alberto Leardini, Lorenzo Chiari, Ugo Della Croce, and Aurelio Cappozzo. 2005. Human movement analysis using stereophotogrammetry: Part 3. Soft tissue artifact assessment and compensation. Gait & posture 21, 2 (2005), 212–225.
[24] Isaac Lara Mekre Mesganaw. 2022. Differences Between Optical and Magnetic Incremental Encoders. Retrieved July 9, 2025 from https://www.ti.com/lit/ab/slya061/slya061.pdf?ts=175271104591 (https://www.ti.com/lit/ab/slya061/slya061.pdf?ts=175271104591)
[25] MertArduino. 2025. How to Build a Motorized 3D Scanning Turntable for Your Phone. Retrieved July 9, 2025 from https://www.instructables.com/How-to-Build-a-Motorized-3D-Scanning-Turntable-for/ (https://www.instructables.com/How-to-Build-a-Motorized-3D-Scanning-Turntable-for/)
[26] Bhavy Metakar. 2025. IMU-Turntable. Retrieved August 2, 2025 from https: //github.com/UpsidedownFalcon/IMU-Turntable
[27] RepRap. 2015. Backlash. Retrieved July 9, 2025 from https://reprap.org/wiki/Backlash (https://reprap.org/wiki/Backlash)
[28] Ltd. Shenzhen Huofeng Technology Co. 2014. Three-Axis Turntable with Thermal Control for IMU Gyro Accelerometer Sensor. Retrieved July 9, 2025 from https: //shenzhenhuofeng.en.made-in-china.com/product/kfoRCbMGkwWN/China-Three-Axis-Turntable-with-Thermal-Control-for-Imu-Gyro-Accelerometer-Sensor.html (https://shenzhenhuofeng.en.made-in-china.com/product/kfoRCbMGkwWN/China-Three-Axis-Turntable-with-Thermal-Control-for-Imu-Gyro-Accelerometer-Sensor.html)
[29] Ltd. Shenzhen Huofeng Technology Co. 2024. Single-Axis Rotary Rate Position Turntable for Imu Gyro Calibration with Thermal Chamber. Retrieved July 9, 2025 from https://shenzhenhuofeng.en.made-in-china.com/product/rZKGcOSWwMtd/China-Single-Axis-Rotary-Rate-Position-Turntable-for-Imu-Gyro-Calibration-with-Thermal-Chamber.html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 (https://shenzhenhuofeng.en.made-in-china.com/product/rZKGcOSWwMtd/China-Single-Axis-Rotary-Rate-Position-Turntable-for-Imu-Gyro-Calibration-with-Thermal-Chamb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)
[30] Downeast Thunder. 2020. DIY Motorized Turntable (FREE PLANS!). Retrieved July 9, 2025 from https://www.homemadetools.net/forum/diy-motorized-turntablefree-plans-82676 (https://www.homemadetools.net/forum/diy-motorized-turntable-free-plans-82676)
[31] Trinamic. 2023. | TMC2209 Datasheet. | Retrieved July 9, 2025 from
https://www.analog.com/media/en/technical-documentation/datasheets/tmc2209_datasheet_rev1.09.pdf (https://www.analog.com/media/en/technical-documentation/data-sheets/tmc2209_datasheet_rev1.09.pdf)
[32] Eduardo Minuzzi Viera, William D’Andrea Fonseca, and Álysson Raniere
Seidel. 2023. | Development of a Turntable for Multidisciplinary Teaching
Applications in Electrical, Electronical, and Acoustical Engineering. | Re-
trieved July 9, 2025 from https://www.researchgate.net/profile/William-Fonseca-4/publication/381485973_Development_of_a_Turntable_for_Multidisciplinary_Teaching_Applications_in_Electrical_Ele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 (https://www.researchgate.net/profile/William-Fonseca-4/publication/381485973_Development_of_a_Turntable_for_Multidisciplinary_Teaching_Applications_in_Electri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)
[33] Jan P Vox, Anika Weber, Karen Insa Wolf, Krzysztof Izdebski, Thomas Schüler, Peter König, Frank Wallhoff, and Daniel Friemert. 2021. An evaluation of motion trackers with virtual reality sensor technology in comparison to a marker-based motion capture system based on joint angles for ergonomic risk assessment. Sensors 21, 9 (2021), 3145.
[34] Sohrob Milani Zadeh, Joy MacDermid, James Johnson, Trevor B Birmingham, and Erfan Shafiee. 2023. Applications of wearable sensors in upper extremity MSK conditions: a scoping review. Journal of NeuroEngineering and Rehabilitation 20, 1 (2023), 158.

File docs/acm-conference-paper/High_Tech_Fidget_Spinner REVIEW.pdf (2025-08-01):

# High-Tech Fidget Spinner: Open-Source 3 Axis Turntable

## Anonymous Author(s)

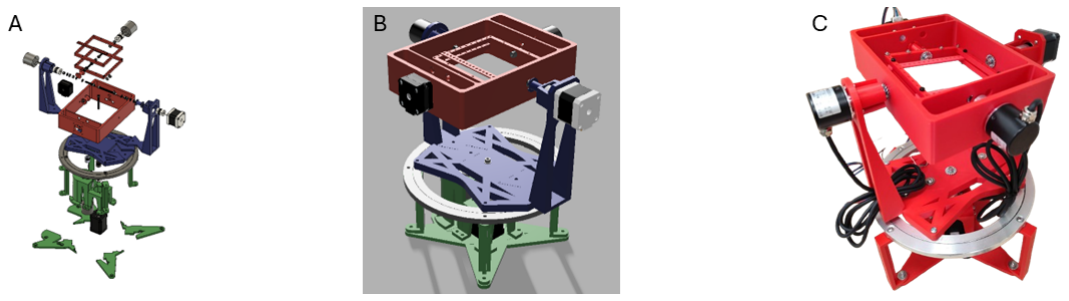
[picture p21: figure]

Figure 1: 3-DoF High-Tech Fidget Spinner exploded view (A), rendered model (B) and working prototype (C).

## Abstract

This paper presents an unprecedented fully open-source, 3-DoF
turntable designed to enable precise characterisation and validation of inertial measurement units (IMUs), for under £500 ($670), which is a fraction of the cost of commercial systems. This design combines 3D-printed mechanical parts, off-the-shelf 3D printer electronics, and custom firmware with a web-based trajectory generator. Users define piecewise motion profiles for roll, pitch, and yaw via a cross-platform GUI; trajectories are saved to MicroSD and executed on a Teensy 4.1-based controller. The system can achieve a mean deviation as small as 0.0075◦
, and can hold a wide range of different IMU devices within a 100mm × 100mm area using its universal mounting fixture. All CAD files (STL/3MF/Fusion 360), electronics schematics, firmware source code, and configuration tools are freely available under the GNU GPLv3 license. This platform lowers the barrier to rigorous IMU testing for researchers, educators, and makers without six-figure budgets, which is what it would cost to purchase a commercial solution.

## CCS Concepts

- Hardware → Semi-formal verification; Semi-formal verification; PCB design and layout.

## Keywords

3D Design, Custom Firwmare, IMU, CAD, PCB Design

ACM Reference Format:
Anonymous Author(s). 2018. High-Tech Fidget Spinner: Open-Source 3 Axis Turntable. In Proceedings of Make sure to enter the correct conference title from your rights confirmation email (Conference acronym ’XX). ACM, New York, NY, USA, 7 pages. https://doi.org/XXXXXXX.XXXXXXX

Permission to make digital or hard copies of all or part of this work for personal or classroom use is granted without fee provided that copies are not made or distributed for profit or commercial advantage and that copies bear this notice and the full citation on the first page. Copyrights for components of this work owned by others than the author(s) must be honored. Abstracting with credit is permitted. To copy otherwise, or republish, to post on servers or to redistribute to lists, requires prior specific permission and/or a fee. Request permissions from permissions@acm.org.
Conference acronym ’XX, Woodstock, NY
© 2018 Copyright held by the owner/author(s). Publication rights licensed to ACM. ACM ISBN 978-1-4503-XXXX-X/2018/06
https://doi.org/XXXXXXX.XXXXXXX

## 1 Introduction 1.1 Motivation and Context

Wearable motion tracking systems increasingly rely on inertial measurement units (IMU sensors) to capture biomechanical kinematics live in the field, outside of laboratory settings. They are a “cost-effective way to measure biomechanical and physiological data... compared to laboratory gold standards" according to Arlotti et al. [1]. The total addressable market (TAM) for wearables grew by 23.1% from 2020 to 2021, reaching $10.28 billion [19], with 84% of devices used for exploring upper extremity musculoskeletal conditions containing IMU sensors [30].
Conventional IMU validation against optical motion capture systems is prone to marker misalignment, frame rate limitations, and soft tissue artifact (STA) in biomechanical contexts [20], producing a reported error of up to ±42°using a VR-based system [29]. Mechanical rigs with rotary encoders (turntables) offer a more accurate ground truth with a relative error below 9% as reported by Jia et al. [17]. Such IMU turntables are commercially available, but they are costly in the 5 to 6-figure USD range with proprietary firmware as shown in Table 1. This causes inconsistent data comparisons across different studies, and high costs hinder reproducible research.

## 1.2 Contributions

To address the aforementioned challenges, this paper presents the “High-Tech Fidget Spinner". It is a fully documented, vendoragnostic and low-cost open-source turntable for IMU characterisation and data validation. This project contributes:
- Hardware and Mechanical Design: A modular 3-DOF gimbal built from 3D-printed PLA parts and off-the-shelf 3D printer components that can execute pre-set trajectories and universally mount any device containing an IMU sensor.
- Electronics and Control: A control system based on a Teensy 4.1 microcontroller with three TMC2209 drivers and rotary encoders to execute a pre-set trajectory and capture the ground truth.
- Firmware and Software: Custom C++ firmware reads binary trajectory files from a MicroSD card, and a Python web app enables intuitive generation of piecewise X/Y/Z profiles.

Conference acronym ’XX, June 03–05, 2018, Woodstock, NY | Anon.
- Open Ecosystem: Full CAD files, BoM, schematics, source
code, and documentation released under the GNU GPLv3
license.
- Validated performance: Customisable and repeatable rotations about 3 axes with sub-degree precision.

## 2 Related Work 2.1 Commercial and Closed-Source IMU Validation Rigs

In Table 1, there is a range of options with varying degrees of freedom, resolution and sample rate. Often, the costs are not listed; however, the costs of the 3LT400 and 13T300 are publicly available and are in the six-figure USD range. Apart from the JAYEGT turntable, the angular resolution of commercial turntables is at least in the order of magnitude of a thousandth of a degree, with their sampling rates ranging from hundreds of hertz to thousands of hertz.
The JAYEGT turntable is a novelty item, often used for photography. It is not designed to calibrate IMU sensors. Although with such a device, the cost barrier is minimal, it would not be suitable for IMU calibration; Its resolution data and sample rate, amongst other things, are not available.

Table 1: Commercially-available turntables

Model | Cost / USD | DoF | Resolution / ° | Sample Rate / Hz
Firepower Control 3LT400 (https://shenzhenhuofeng.en.made-in-china.com/product/kfoRCbMGkwWN/China-Three-Axis-Turntable-with-Thermal-Control-for-Imu-Gyro-Accelerometer-Sensor.html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) [24] | 210, 000.00 | 3 | 0.000833 | 80

Firepower
Control
2TS-450[3] (https://www.accelerometergyro.com/sale-30377756-remote-control-position-rate-turntable-for-ins-imu-test-and-calibration.html)
NA | 2 | 0.006 | 1000

Blue Equator
BE-INS2-
22D08 (https://blueequator-ai.com/products/high-precision-automated-dual-axis-positioning-turntable-for-optical-measurement,-aerospace,-and-robotics-calibration) [9]
NA | 2 | 0.00139 | NA

Firepower
Control
1LT300 (https://shenzhenhuofeng.en.made-in-china.com/product/rZKGcOSWwMtd/China-Single-Axis-Rotary-Rate-Position-Turntable-for-Imu-Gyro-Calibration-with-Thermal-Chamb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) [25]
180, 000.00 | 1 | 0.0001 | 100

iMAR iTES-PDT07[14] (https://www.imarnavigation.de/downloads/TES_PDT07_turntable.pdf)

NA | 1 | 0.00153 | NA

iMAR
iTURN-2D1-
HIL[13] (https://imar-navigation.de/en/product/iturn-2)
NA | 2 | 5.56 × 10⁻⁶
1000

iMAR
iTURN-3S1[12] (https://www.imar-navigation.de/downloads/TURN-3S1.pdf)
NA | 3 | 0.0002 | 1000

JAYEGT
Motorized
Rotating
Display
Stand[16] (https://www.amazon.co.uk/JAYEGT-Motorized-Rotating-Turntable-Photography/dp/B08QS6YTHK)
41.90 | 1 | NA | NA

## 2.2 DIY and Academic IMU Validation Rigs

There are free plans available on the internet for DIY 1 DoF turntable builds [11] [22] [26], and Viera et al. describe the construction of a simple turntable [28].
Some designs available online employ 3D-printed gear mechanisms [11] [22]. Such mechanisms are not suitable for a turntable designed to characterise and validate IMU data due to the non-zero backlash [7].
Other designs [26] [28] employ a direct connection between the rotational actuator shaft and turntable. Under the conditions of a properly fastened connection, the backlash issue with gear transmissions is eliminated. However, the designs do not include any rotary encoders to provide a ground truth to compare the IMU data against.

## 2.3 Open-Source Hardware in Wearables

Open-source hardware should be findable, accessible, interoperable and reproducible [2]. With commercial solutions, they are findable but not accessible due to their cost, not interoperable due to their proprietary firmware and not reproducible due to companies’ intellectual property rights. DIY solutions are often findable, accessible, interoperable with modifications and reproducible, but they are not fit for IMU characterisation and validation.

## 3 Artifact Overview 3.1 Design Goals

From studying the Related Work, the following design goals were chosen to fill in the gaps identified:
- 3 DoF to provide more functionality than some commercial options.
- Logging synchronous IMU and absolute rotation data to be able to calculate error statistics.
- Fully documented, following the FAIR principles [2] and has a minimal cost.
- 360°of continuous rotation about each rotational axis, like commercial solutions in Table 1.
- A rotational actuation resolution up to 0.05625°to match the maximum possible resolution by Viera et al. [28].
- Bespoke user-defined trajectories for versatility.

## 3.2 System Architecture

A browser GUI (HTML/CSS/JS frontend, Python/Flask backend) lets users define bespoke piecewise motion profiles and stepper-motor parameters. It discretises each axis’s trajectory into timed anglestep binaries, saves them to a MicroSD card, and the Teensy 4.1 controller (with TMC2209 drivers) loads and executes them on the X, Y, and Z steppers. During operation, the controller logs actual angles via rotary encoders, and IMU data can stream over UART, I2C, or SPI — or be logged separately.

## 3.3 Licensing and Repository

This High-Tech Fidget Spinner is licensed under the GNU GPLv3 which lets the community use the project however they wish, apart from distributing it as closed-source versions. It can be found on GitHub via the following URL:

High-Tech Fidget Spinner: Open-Source 3 Axis Turntable | Conference acronym ’XX, June 03–05, 2018, Woodstock, NY

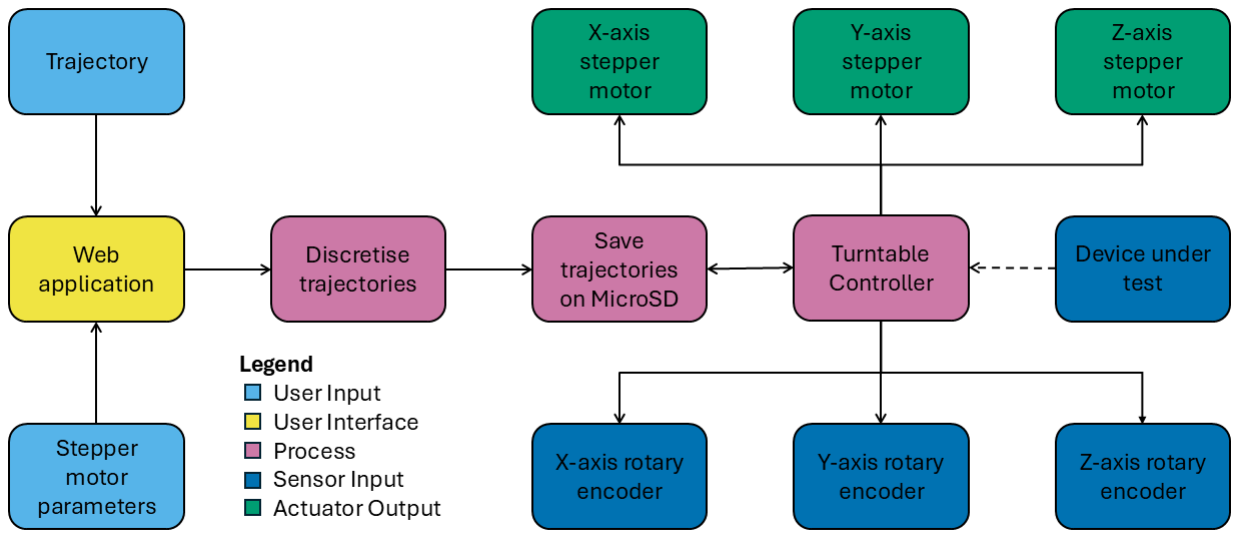
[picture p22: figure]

Figure 2: Browser GUI exports user’s trajectories as motion binaries to MicroSD, which the artifact executes.

https://github.com/UpsidedownFalcon/IMU-Turntable The README file contains the repository structure; there is a detailed assembly; there is a post-assembly checklist, and a usage guide on the GitHub.

## 4 Mechanical Design

The High-Tech Fidget Spinner consists of a 3-DOF gimbal structure with motor and sensor mounts. A rotating base provides rotation about the Z axis. On top of the rotating base, two other orthogonal rotation systems are mounted for rotation about the X and Y axes. A direct connection between the stepper motors and rotating body was chosen instead of a mechanism such as gearboxes or pulleys to remove the backlash found in such systems [7]. Bearings and a lazy susan have been used to support each frame of rotation, ensure each frame rotates only about its axis and to ensure that the axes of rotation are orthogonal.
All of the rotational frames and brackets were 3D printed on a Bambulabs X1E 3D printer out of PLA with a 0.2mm layer height and 15% infill. The clamping parts for the universal mounting fixture were 3D printed on an Ender 5 out of 85A TPU with a 0.2mm layer height and 20% infill.

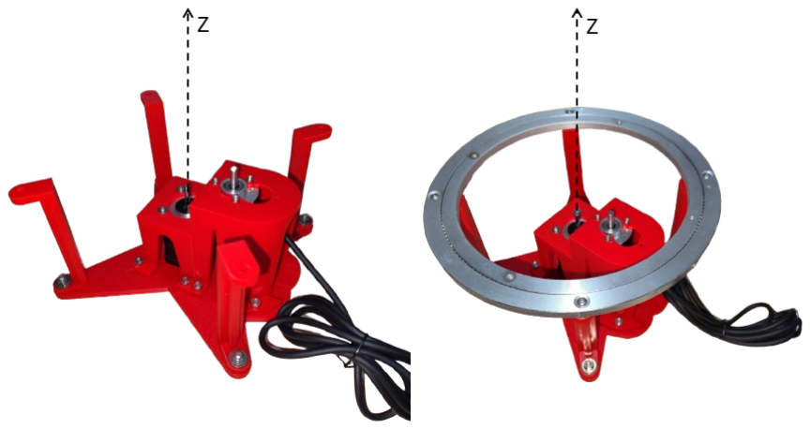
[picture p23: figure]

Figure 3: Base frame sub-assembly (left) for rotation about the Z-axis. A lazy susan (right) adds stability to the sub-assemblies mounted on the base.

Figure 3 shows the base sub-assembly with 4 vertical posts; a bracket for the base stepper motor; a bracket for the base rotary encoder and a lazy susan. The vertical posts are mounts for the lazy susan, which provides stability for additonal sub-assemblies mounted on top of the base. The base stepper motor rotates the device under test (DUT) about the Z-axis and the base rotary encoder measures the rotation about the Z-axis. The rotary encoder is connected to the stepper motor via a GT20 timing belt due to their little backlash, as the “ backlash is distributed over a full half turn rather than happening immediately on direction change" [23]. Due to practical design considerations of a direct connection between the Z-axis rotary encoder and rotating sub-assemblies on top of the base, the rotary encoder was driven by a timing belt and pulley system rather than a direct drive.

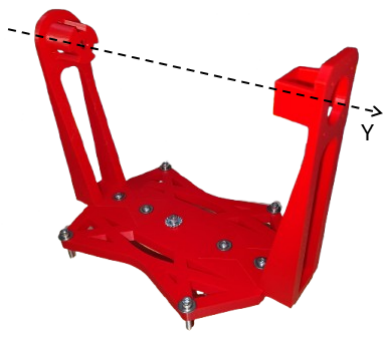
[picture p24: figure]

Figure 4: Middle frame sub-assembly for rotation about the Y-axis.

Figure 4 shows the middle sub-assembly with a mount to the lazy susan on the base; stepper motor mount and a rotary encoder mount. It can be mounted to the lazy susan on the base to ensure stable rotation in the X-Y plane, and a stepper motor and rotary encoder can be mounted along the Y-axis. This allows for rotation about the Y-axis and its measurement.


Figure 5: Inner frame sub-assembly for rotation about the X-axis.

Figure 5 shows the inner sub-assembly with a mount for the DUT; stepper motor mount; a rotary encoder mount and a mount to the middle assembly. The mount to the middle assembly is a pair of M5 machine screws which attach to the Y-axis stepper motor and rotary encoder through a set of bearings. The inner assembly can be connected to a stepper motor and rotary encoder to rotate the DUT about the X-axis and measure its rotation. The mount for the DUT forms part of the universal mounting fixture, with its other part being 3D-printed out of TPU.
Figure 1 shows the complete mechanical assembly of the High-Tech Fidget Spinner with a single point of rotation in the middle of the inner frame about three orthogonal axes. Its cost is under £500 ($670).
Figure 6 shows the second half of the universal mounting fixture which is 3D printed out of TPU and attached to the inner frame.


Figure 6: Universal mounting fixture made out of TPU (left) attached to the inner frame (right).

The user can configure how many TPU mounts they need, where to place them and their tension using the holes in the TPU mount and the inner frame. The TPU mount is attached to the inner frame using M3 machine screws.


Figure 7: A watch (left), a multitool (middle) and a CO2 canister (right) secured using the universal mounting fixture.

Figure 7 shows the universal mounting fixture securely holding a watch, a multitool and a CO2 canister to demonstrate that it can hold a range of different objects, and hence, a range of IMU devices. The user has flexibility over where and how to place their object for their bespoke application.

## 5 Electronics and Firmware 5.1 Stepper Motor Selection

5.1.1 Stepper Motors. To meet the rotational requirements of a 3-axis rig with ≥ 360°range and ≤ 0.05625°resolution, open-loop stepper motors were selected due to their high native angular precision, ease of control, and widespread availability in open-source hardware ecosystems [5]. Standard stepper motors typically offer step angles of 1.8

◦
(200 steps/rev) or 0.9

◦
(400 steps/rev); combined
with microstepping up to 1/256, resolutions as fine as 0.0035◦ per microstep are attainable without the need for encoders [6]. Stepper drivers such as the TMC2209 interface via simple STEP/DIR signals, eliminating the complexity of feedback control systems used in DC or BLDC motors [27].

5.1.2 Dynamic Torque Modeling. Table 1 shows commercial IMU turntables that have angular accelerations in the order of magnitude of 1000 − 10000°/s

2
. However, Firepower Control’s 2TS-450 IMU turntable has an angular acceleration of 300°/s

2
[3]. To match that
angular acceleration of 300◦
/s

2
(≈ 5.236 rad/s

2
), each axis was
modelled as a compound rigid body composed of rotor inertias and the inertia of the IMU payload. The IMU, modelled as a 15.25 mm long, 11.86 g rod, yields a moment of inertia of 1.38 × 10⁻⁶ kg · m²
. Detailed models and calculations are explained in the PRD.md document on GitHub.

Torque requirements for each axis were computed as follows using a custom Python script, Stepper_Selection_Model.py, which can be found on GitHub:

- X-axis: τ = (2IRX + IIMU) · α
- Y-axis: τ =
1
12 (2MX + MIMU)L

2 + 2IRY
- α
- Z-axis: τ =
1
2

(2MX + 2MY + MIMU)R

2 + 2IRZ
- α

A safety factor of 10× was applied to each calculated torque to ensure robustness under dynamic loading.

5.1.3 Selected Motors. The custom Python script was used to search and evaluate commercially available stepper motors, filtering for those that meet the required torque, size, and inertia constraints with adequate margin and lead time. The selected models are:

- X-axis: Nema 17 42-23
- Y-axis: Nema 17 42-38
- Z-axis: Nema 17 42-60

Anyone can use Stepper_Selection_Model.py to locate suitable stepper motors which they can easily source form their local suppliers.

5.1.4 Microcontroller, Drivers and Rotary Encoders. In order for the High-Tech Fidget Spinner to be as versatile as possible, the user should be able to connect their own IMU sensor to its controller and add to the firmware to log data over any digital communication protocol they choose. Commercial IMU turntables in Table 1 often have CAN bus connectors, which not all data logging devices (for example laptops) have, and there are inconsistent USB ports and protocols between data logging devices. Different data loggers may use different standards such as CAN bus, SDI-12 and MODBUS. Since there is no single data logging standard [10], there may be interoperability and versatility issues if the High-Tech Fidget Spinner depended on one. Hence, the High-Tech Fidget Spinner must be able to independently function, which will require its own onboard storage for saving logged data.
Dynamic current control ensures smooth stepper performance under varying loads, and having the option for the maximum of256-microstep drivers can maximise angular resolution and versatility. Optical rotary encoders have a greater accuracy and resolution than magnetic rotary encoders [21]. The resolution of an optical rotary encoder can be described by the number of pulses per revolution (PPR), counts per revolution (CPR) or lines per revolution (LPR) [4].
The following components were chosen for the High-Tech Fidget Spinner controller board from the requirements discussed previously:
- Microcontroller: Teensy 4.1 due to its plethora of assignable GPIO for UART, I2C and SPI, and a built-in MicroSD card slot [15].
- Stepper motor driver: TMC2209 due to its SpreadCycle chopper and 256 microstepping resolution [27].
- Rotary encoder: E38S6G5-100B-G24N optical rotary encoder.


Figure 8: Schematic of the controller for the High-Tech Fidget Spinner.


Figure 9: Web app with input fields and discretisation (right), and visual trajectories (centre and left).

## 5.2 Schematic

Figure 8 shows the controller schematic consisting of a Teensy 4.1 microcontroller, three TMC2209 drivers and generic pin connectors to the stepper motors and rotary encoders.
The PCB layout is available on GitHub alongside the KiCad 9.0 project files. To reproduce the project, the controller board can also be constructed on a breadboard. An external power supply (≥ 120W ) is required to supply +24V and +5V .

## 5.3 Code Explanation

The web app GUI shown in Figure 9 allows the user to:
- Adjust their stepper motor parameters.
- Enter a trajectory as a piecewise function for each axis of rotation.
- Swap between the axes of rotation.
- Plot the trajectory entered.
- Discretise and save the trajectories onto a MicroSD card once all of them have been entered.
Figure 10 shows the change between processes due to user inputs. The user can define bespoke trajectories as continuous piecewise functions. The mathematics used to discretise them into executable stepper motor trajectories is as follows:

5.3.1 User Input and Function Parsing. Each motor axis M ∈ {X, Y, Z} accepts a piecewise-defined angular trajectory as a set of symbolic


Figure 10: Web application interaction flow diagram.

functions fi(t) defined over domains [ai
, bi]. These functions are parsed and converted into numerical callables using symbolic mathematics:

fi(t) = sympify(user input), f num i
(t) = lambdify(fi(t), numpy) (1)

5.3.2 Angular Resolution and Discretisation Step Size. The system computes the angular resolution per microstep:

θres =

θstep

μ

(2)

where θstep is the step angle (in degrees) and μ is the number of microsteps.
The angular trajectory is initially sampled at 1,000 uniform time points to compute the maximum angular velocity via first-order finite differences:

vmax = max

dθ

dt

≈ max
j

θ j+1 − θ j

tj+1 − tj

(3)

The discretisation time step dt is then computed as:

dt = max
θres

vmax

, dtmin
(4)

where dtmin is a fixed lower bound to prevent oversampling (e.g., dtmin = 0.002 s).

5.3.3 Sampling and Trajectory Construction. For each segment f

num
i

∈ [ai

, bi], we compute the number of samples:

Ni =

bi − ai
dt |
+ 1 | (5)

The time samples are then uniformly spaced:

tj ∈ linspace(ai
, bi

, Ni), θ j = f

num
i
(tj) | (6)

The full trajectory is constructed by concatenating all segments while avoiding duplicate boundary points.

5.3.4 Velocity and Acceleration Profiling. Given the discretised angular positions θ j

, the velocity and acceleration profiles are computed numerically via finite differences:

ωj =

θ j+1 − θ j
dt | (7)

αj =

ωj+1 − ωj
dt | (8)

These profiles are plotted and visualised for motion quality analysis.

5.3.5 Validation and Export. The discretisation process is only enabled once valid input functions and domains are defined for all three axes X, Y, Z. Upon triggering, the discretised trajectories are stored as interleaved binary sequences:

[uint32 N] [float32 t0, θ0, t1, θ1, . . . , tN −1, θN −1] | (9)
These files are written to an SD card and interpreted by a microcontroller for real-time motor control.

## 6 Evaluation and Benchmarking 6.1 Method

Infrared reflectors were placed on the High-Tech Fidget Spinner. An Optitrak Prime X 22 motion capture system was used to capture its motion while performing a step trajectory from 0

◦

to 90◦
| in
increments of 10◦

## 6.2 Results


Figure 11: Euler angles of the X-axis (top), Y-axis (middle) and Z-axis (bottom) rotation.

Figure 11 plots X-axis rotation under the stepped trajectory, where non-zero start and end velocities cause oscillatory motion and an increasing range over time.
The Y-axis is plotted from 0

◦

to −90◦
, per the defined rotation direction relative to the motion capture coordinate system. It ends with a large oscillation due to a manual Y-axis reset.

The Z-axis follows a similar trend as the X-axis, but with a smaller range over time. This is due to a smaller oscillation amplitude about the Z-axis as the bodies rotating about it have a larger moment of inertia due to a greater cumulative mass.
Table 2 gives summary statistics for the errors:

Table 2: Error analysis

| X-axis | Y-axis | Z-axis
Smallest mean deviation / ° | -0.075 | 0.08 | 0.18
Largest mean deviation / ° | -0.87 | 1.17 | 0.34
Smallest range / ° | 0.01 | 0.008 | 0.04
Largest range / ° | 1.4 | 5.2 | 2.3

## 6.3 Discussion

There were random errors present in the experiment, as the infrared reflectors were manually placed and stuck on using tape. Due to this, there are random errors in marker alignment and since the tape did not create a perfectly rigid joint, the markers underwent harmonic oscillations during acceleration which is shown by the data plotted in Figure 11.
The trajectory chosen was a step trajectory with a linear ramp between each step. This leads to a non-zero starting and ending velocity, and hence, jerky motion. The largest ranges were observed during harmonic oscillation when the High-Tech Fidget Spinner first started moving upon being powered on. The jerky motion due to the trajectory coupled with the stepper motors jumping to their nearest full steps, are likely reasons behind the largest ranges being one to two orders of magnitude larger than the smallest ranges.

## 6.4 Future Work

To address the jerky motion issue, it would be beneficial to explore what effect higher-order polynomial trajectories [18] have on a low-cost and open-source IMU calibration turntable. A closed-loop control system for the stepper motors, such as PID control, remains to be explored for more accurate motions [8].

## 7 Conclusion

Combining 3D-printed components, off-the-shelf 3D printer hardware, and open-source firmware, the artifact achieves 0.075◦ mean deviation with 0.008◦
range (Table 2) - within an order of magnitude of commercial systems like the Firepower Control 2TS-450 (Table 1), while remaining fully findable, accessible, interoperable, and reproducible. This unprecedented, high-precision design democratises advanced IMU testing — all for under £500.

## References

[1] Jacob S Arlotti, William O Carroll, Youness Afifi, Purva Talegaonkar, Luciano Albuquerque, John E Ball, Harish Chander, Adam Petway, et al. 2022. Benefits of IMU-based wearables in sports medicine: Narrative review. International Journal of Kinesiology and Sports Science 10, 1 (2022), 36–43.
[2] Michelle Barker, Neil P Chue Hong, Daniel S Katz, Anna-Lena Lamprecht, Carlos Martinez-Ortiz, Fotis Psomopoulos, Jennifer Harrow, Leyla Jael Castro, Morane Gruenpeter, Paula Andrea Martinez, et al. 2022. Introducing the FAIR Principles for research software. Scientific Data 9, 1 (2022), 622.

[3] Firepower Control. 2025. Remote Control Position Rate Turntable For INS IMU Test And Calibration 2TS-450. https://www.accelerometergyro.com/sale-30377756-remote-control-position-rate-turntable-for-ins-imu-test-andcalibration.html. (https://www.accelerometergyro.com/sale-30377756-remote-control-position-rate-turntable-for-ins-imu-test-and-calibration.html) Accessed: 2025-07-09.
[4] Zhang Daniel. [n. d.]. What is the difference between incremental encoder’s PPR, CPR and LPR? https://www.omc-stepperonline.com/support/what-is-thedifference-between-incremental-encoder-s-ppr-cpr-and-lpr. (https://www.omc-stepperonline.com/support/what-is-the-difference-between-incremental-encoder-s-ppr-cpr-and-lpr) Accessed: 2025-07-09.
[5] Clarence W De Silva. 2004. An Integrated Approach. Boca Raton, FL: CRC Press.
[6] Analog Devices. 2020. | Mastering Precision: Understanding Mi-
crostepping in Motion Control. | Analog Dialogue (2020). | https:
//www.analog.com/en/resources/analog-dialogue/articles/mastering-precisionunderstanding-microstepping.html (https://www.analog.com/en/resources/analog-dialogue/articles/mastering-precision-understanding-microstepping.html) Microstepping benefits and open-loop precision.
[7] Philipp Eisele, Sajid Nisar, and Franz Haas. 2024. A conceptual examination of an additive manufactured high-ratio coaxial gearbox. Artificial Life and Robotics 29, 3 (2024), 416–422.
[8] Nehal M Elsodany, Sohair F Rezeka, and Noman A Maharem. 2011. Adaptive PID control of a stepper motor driving a flexible rotor. Alexandria Engineering Journal 50, 2 (2011), 127–136.
[9] Blue Equator. 2021. High-Precision Automated Dual-Axis Positioning Turntable for INS & IMU Calibration. https://blueequator-ai.com/products/high-precisionautomated-dual-axis-positioning-turntable-for-optical-measurement,-aerospace,-and-robotics-calibration. (https://blueequator-ai.com/products/high-precision-automated-dual-axis-positioning-turntable-for-optical-measurement,-aerospace,-and-robotics-calibration) Accessed: 2025-07-09.
[10] Sina Gholamian and Paul AS Ward. 2021. A comprehensive survey of logging in software: From logging statements automation to log mining and analysis. arXiv preprint arXiv:2110.12489 (2021).
[11] Handy_Bear. 2022. How to Make a Motorized Lazy Susan With a Secret. https://www.instructables.com/How-to-Make-a-Motorized-Lazy-Susan-With-a-Secret/. (https://www.instructables.com/How-to-Make-a-Motorized-Lazy-Susan-With-a-Secret/) Accessed: 2025-07-09.
[12] iMAR Navigation & Control. 2017. iMAR iTURN-3S1. https://www.imar-navigation.de/downloads/TURN-3S1.pdf. (https://www.imar-navigation.de/downloads/TURN-3S1.pdf) Accessed: 2025-07-09.
[13] iMAR Navigation & Control. 2024. iMAR iTURN-2D1-HIL. https://www.imar-navigation.de/downloads/TURN-2.pdf. (https://www.imar-navigation.de/downloads/TURN-2.pdf) Accessed: 2025-07-09.
[14] iMAR Navigation & Control. 2025. iTES-PDT-07. https://www.imar-navigation.de/downloads/TES_PDT07_turntable.pdf. (https://www.imar-navigation.de/downloads/TES_PDT07_turntable.pdf) Accessed: 2025-07-09.
[15] Adafruit Industries. [n. d.]. PJRC Teensy 4.1 Development Board. https://mm.digikey.com/Volume0/opasdata/d220001/medias/docus/425/4622_Web.pdf. (https://mm.digikey.com/Volume0/opasdata/d220001/medias/docus/425/4622_Web.pdf) Accessed: 2025-07-09.
[16] JAYEGT. 2020. JAYEGT Motorized Rotating Display Stand, 7.87inch /17.6lbs Load, 360 Degree Electric Rotating Turntable for Photography Products, Jewelry, Cake,3D Model ,Mirror Cover (White). https://www.amazon.co.uk/JAYEGT-Motorized-Rotating-Turntable-Photography/dp/B08QS6YTHK. (https://www.amazon.co.uk/JAYEGT-Motorized-Rotating-Turntable-Photography/dp/B08QS6YTHK) Accessed: 2025-07-09.
[17] Hua-Kun Jia, Lian-Dong Yu, Hui-Ning Zhao, and Yi-Zhou Jiang. 2019. A new method of angle measurement error analysis of rotary encoders. Applied Sciences 9, 16 (2019), 3415.
[18] Hossein Barghi Jond, Vasif V Nabiyev, and Rifat Benveniste. 2016. Trajectory planning using high order polynomials under acceleration constraint. Journal of Optimization in Industrial Engineering 10, 21 (2016), 1–6.
[19] Min Jung Kang and Yong Cheol Hwang. 2022. Exploring the factors affecting the continued usage intention of IoT-based healthcare wearable devices using the TAM model. Sustainability 14, 19 (2022), 12492.
[20] Alberto Leardini, Lorenzo Chiari, Ugo Della Croce, and Aurelio Cappozzo. 2005. Human movement analysis using stereophotogrammetry: Part 3. Soft tissue artifact assessment and compensation. Gait & posture 21, 2 (2005), 212–225.
[21] Isaac Lara Mekre Mesganaw. 2022. Differences Between Optical and Magnetic Incremental Encoders. https://www.ti.com/lit/ab/slya061/slya061.pdf?ts=175271104591. (https://www.ti.com/lit/ab/slya061/slya061.pdf?ts=175271104591) Accessed: 2025-07-09.
[22] MertArduino. 2025. How to Build a Motorized 3D Scanning Turntable for Your Phone. https://www.instructables.com/How-to-Build-a-Motorized-3D-Scanning-Turntable-for/. (https://www.instructables.com/How-to-Build-a-Motorized-3D-Scanning-Turntable-for/) Accessed: 2025-07-09.
[23] RepRap. 2015. Backlash. https://reprap.org/wiki/Backlash. Accessed: 2025-07-09.
[24] Ltd. Shenzhen Huofeng Technology Co. 2014. Three-Axis Turntable with Thermal Control for IMU Gyro Accelerometer Sensor. https://shenzhenhuofeng.en.madein-china.com/product/kfoRCbMGkwWN/China-Three-Axis-Turntable-with-
Thermal-Control-for-Imu-Gyro-Accelerometer-Sensor.html. (https://shenzhenhuofeng.en.made-in-china.com/product/kfoRCbMGkwWN/China-Three-Axis-Turntable-with-Thermal-Control-for-Imu-Gyro-Accelerometer-Sensor.html) | Accessed:
2025-07-09.
[25] Ltd. Shenzhen Huofeng Technology Co. 2024. Single-Axis Rotary Rate Position Turntable for Imu Gyro Calibration with Thermal Chamber. https: //shenzhenhuofeng.en.made-in-china.com/product/rZKGcOSWwMtd/China-Single-Axis-Rotary-Rate-Position-Turntable-for-Imu-Gyro-Calibration-with-Thermal-Chamber.html?pv_id=1ivd6vdqb9d2&faw_id=1ivd6veb0bc3&bv_id= 1ivd704253ac&pbv_id=1ivd6vbrf001. (https://shenzhenhuofeng.en.made-in-china.com/product/rZKGcOSWwMtd/China-Single-Axis-Rotary-Rate-Position-Turntable-for-Imu-Gyro-Calibration-with-Thermal-Chamb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) Accessed: 2025-07-09.
[26] Downeast Thunder. 2020. DIY Motorized Turntable (FREE PLANS!). https://www.homemadetools.net/forum/diy-motorized-turntable-free-plans-82676. Accessed: 2025-07-09.
[27] Trinamic. 2023. TMC2209 Datasheet. https://www.analog.com/media/en/technical-documentation/data-sheets/tmc2209_datasheet_rev1.09.pdf. (https://www.analog.com/media/en/technical-documentation/data-sheets/tmc2209_datasheet_rev1.09.pdf) Accessed: 2025-07-09.
[28] Eduardo Minuzzi Viera, William D’Andrea Fonseca, and Álysson Raniere Seidel. [n. d.]. Development of a Turntable for Multidisciplinary Teaching Applications in Electrical, Electronical, and Acoustical Engineering. ([n. d.]).
[29] Jan P Vox, Anika Weber, Karen Insa Wolf, Krzysztof Izdebski, Thomas Schüler, Peter König, Frank Wallhoff, and Daniel Friemert. 2021. An evaluation of motion trackers with virtual reality sensor technology in comparison to a marker-based motion capture system based on joint angles for ergonomic risk assessment. Sensors 21, 9 (2021), 3145.
[30] Sohrob Milani Zadeh, Joy MacDermid, James Johnson, Trevor B Birmingham, and Erfan Shafiee. 2023. Applications of wearable sensors in upper extremity MSK conditions: a scoping review. Journal of NeuroEngineering and Rehabilitation 20, 1 (2023), 158.

Received 20 February 2007; revised 12 March 2009; accepted 5 June 2009

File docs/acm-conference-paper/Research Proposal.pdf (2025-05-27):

# Research Proposal for Open-Source Turntable: Creating a Unified

# Technique to Validate IMU Sensor Data

Metakar, Bhavy

April 2025

## Contents

1 Introduction | 2
2 Literature Review | 3
3 Research Title | 4
4 Project Specifics | 4
5 Component Selection | 4
6 Methodology | 4
7 Timeline | 5
8 Expected Contribution | 5

Abstract

Inertial Measurement Units (IMUs) are critical tools in wearable motion tracking systems for biomechanical

analysis. Despite recent advancements in high-frequency data acquisition (500Hz - 1kHz+), the accuracy of

IMUs operating at such rates remains underexplored - particularly when validated against controlled mechan-

ical motion. This proposal aims to design a high-frequency IMU acquisition system, develop an open-source

mechanical validation jig for known-motion testing, and analyse orientation, angular velocity, and acceleration

data accuracy using statistical error models. The findings will contribute to the development of high-precision,

real-time wearable systems for medical and sports applications.

## 1 Introduction

Wearable technologies increasingly rely on inertial measurement units (IMUs) to quantify human motion. IMUs

are “a cost-effective way to measure biomechanical and physiological data . . . compared to laboratory gold standards” [1]. The total addressable market (TAM) for wearables grew by 23.1% from 2020 to 2021, reaching $10.28 billion [2], creating commercial pressure for faster, more reliable sensing. Hippos Exoskeleton Incorporated

[3], for example, is developing a soft exoskeleton to prevent anterior cruciate ligament (ACL) injuries. An ACL rupture initiates within roughly 60 ms [4][5], while the company’s proprietary actuator requires about 40ms to

generate protective torque, leaving a sensing and decision-making budget of at most 20ms. The sample time -defined as the interval needed to acquire and preprocess one frame of IMU data - must stay within 20ms. This necessitates a sampling rate of well over 50Hz - ideally in at least the range of 500 − 1000Hz, together with minimal preprocessing latency, to process multiple frames of IMU data (10 − 20× [6]) for accurate filtering and

processing. High-frequency measurements must also be accurate so that physiological decisions are trustworthy.

Despite abundant work on IMUs sampled at ≤ 500Hz, comparatively little research investigates, or rigorously validates, IMU performance above this range (500−1000Hz and beyond). Higher sampling rates have been shown to reduce root-mean-square error (RMSE) [7], yet most studies benchmark IMUs against optical motion-capture systems whose limited video capturing frame rate (often 240fps = 240Hz) and marker placement errors can inflate kinematic inaccuracies to 42% [8]. Such errors obscure true IMU performance at 1kHz. Mechanical rigs outfitted with high-resolution rotary encoders achieve relative errors below 9% [9] and therefore represent a more suit-

able ground truth, but they have not been leveraged to characterise wearable IMUs operating at high frequencies.

In this proposal, I outline the design and fabrication of an open-source turntable to more accurately validate high-frequency IMU data acquisition. This work will contribute to the work that has been ongoing for the past year at Hippos Exoskeleton [3], which has been around injury prediction from IMU data.
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

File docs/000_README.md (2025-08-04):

# ```/docs/``` 

This directory is full of documentation about the conference paper, a project development log and instrutions on how to use the High-Tech Fidget Spinner. 

```
├── acm-conference-paper/          # Files for https://doi.org/10.1145/3714394.3756256  
├── development-log/               # Contains rationale for design decisions 
├── how-to-use.md                  # Guide explaining how to use the High-Tech Fidget Spinner 
└── README.md 
``` 

Once you have a fully-constructed High-Tech Fidget Spinner, you can read through [```./how-to-use.md```](/docs/how-to-use.md) to start using it!

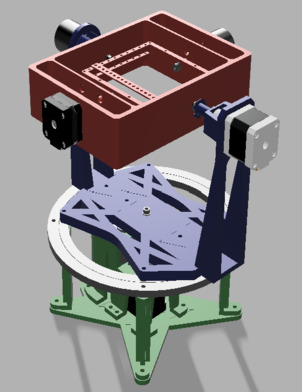
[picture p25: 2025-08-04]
docs/acm-conference-paper/Thumbnail.jpg

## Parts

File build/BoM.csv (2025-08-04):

Link | Component | Description | Quantity | Unit Cost / £ | Additional Cost / £ | Total Cost / £ | Notes | Net cost / £
https://www.amazon.co.uk/dp/B07R8VSMQH | Rotary encoders | 600P/R Rotary Encoder, Incremental Rotary Encoder Module, DC 5-24v 2 Phase | 3 | 20.48 | 0.00 | 61.44 | - | 416.12
https://www.amazon.co.uk/dp/B07WC71M4R | Stepper drivers | BIGTREETECH TMC2209 V1.3 Stepper Motor Driver | 1 | 33.99 | 0.00 | 33.99 | -
https://www.amazon.co.uk/dp/B0DDJ9X16R | M5 x 50 | Socket Head Cap Screws - [M5-0.8 x 50mm] 304 Stainless Steel | 1 | 9.99 | 0.00 | 9.99 | -
https://www.amazon.co.uk/dp/B01EV70C78 | Jumper wires | ELEGOO 120pcs Multicolored Dupont Wire 40pin Male to Female, 40pin Male to Male, 40pin Female to Female | 1 | 6.29 | 0.00 | 6.29 | -
https://www.amazon.co.uk/dp/B07YJTFVB2 | Breadboard | 830 Ties Solderless Protype Breadboard | 1 | 6.99 | 0.00 | 6.99 | -
https://www.amazon.co.uk/dp/B0B2W9S3PY | Timing belt | GT20 Timing Belts 122mm Closed Loop Synchronous 6mm Width | 1 | 5.69 | 0.00 | 5.69 | -
https://www.amazon.co.uk/dp/B0DK3RJ793 | 5mm pulley s | 20 Teeth 5mm Bore 6mm Width Timing Belt Pulley | 1 | 7.19 | 0.00 | 7.19 | -
https://www.amazon.co.uk/dp/B0CJ2F6P5L | 6mm pulleys | 20 Teeth 6mm Bore 16mm Dia. Aluminum Timing Belt Pulley | 1 | 9.49 | 0.00 | 9.49 | -
https://www.amazon.co.uk/dp/B0BGXTNB5M | M5 washers | M5 Washers, M5 x 15mm Penny Washers | 1 | 8.29 | 0.00 | 8.29 | -
https://www.amazon.co.uk/dp/B0CSFLS56R | M3 washers | M3 Washers 100Pcs, M3 x 9mm Penny Washers | 1 | 5.48 | 0.00 | 5.48 | -
https://www.amazon.co.uk/dp/B09VPPRS8T | Turntable bearing | Rotating Bearing Turntable, Ball Bearing Rotating Table, Smooth Swivel Plate, Table Top Rotating Turntable, for Kitchen, Living Room, Dining Table, Easy to Assemble, Non-Slip Rubber Feet, 25 cm | 1 | 16.55 | 0.00 | 16.55 | -
https://www.amazon.co.uk/dp/B0CK25DZZT | M5 x 30 | M5 X 30mm Allen Socket Head Cap Screws | 1 | 5.79 | 0.00 | 5.79 | -
https://www.amazon.co.uk/dp/B08KPBSF3Q | M5 hex nuts | M5 (5mm) Hex Full Nut - A2 Stainless Stee | 1 | 4.99 | 0.00 | 4.99 | -
https://www.amazon.co.uk/dp/B0D949NBBG | M5 x 25 | M5 X 25mm Socket Head Cap Screws Bolts DIN 912 (ISO 4762) 304 Stainless Steel | 1 | 5.99 | 0.00 | 5.99 | -
https://www.amazon.co.uk/dp/B0BFJ7MWW4 | M5 toothed washers | M5 Serrated Shakeproof Washer Lock Washers | 1 | 4.99 | 0.00 | 4.99 | -
https://www.amazon.co.uk/dp/B08H27FFQN | 5 x 9 x 3 ball bearing | MR95-2RS Deep Groove Ball Bearings 5mm x 9mm x 3mm | 1 | 9.99 | 0.00 | 9.99 | -
https://www.amazon.co.uk/dp/B0DBR8N5S4 | 5 x 5 flexible coupling | Aluminum Alloy Shaft Coupling 5mm to 5mm | 1 | 12.49 | 0.00 | 12.49 | -
https://www.amazon.co.uk/dp/B07G6T4YYF | 5 x 6 flexible coupling | 5mm to 6mm Aluminum Alloy Shaft Coupling | 2 | 8.39 | 0.00 | 16.78 | -
https://www.amazon.co.uk/dp/B097PD2JW3 | Nema 17 42-60 | iMetrx Nema 17 Stepper Motor 42x60mm | 1 | 22.99 | 0.00 | 22.99 | -
https://www.amazon.co.uk/dp/B097JJZF46 | Nema 17 42-38 | iMetrx Nema 17 Stepper Motor 42x38mm | 1 | 24.99 | 0.00 | 24.99 | -
https://www.amazon.co.uk/dp/B0C36D34F5 | Nema 17 42-23 | iMetrx Nema 17 Stepper Motor 42x23mm Pancake Motor | 1 | 10.50 | 0.00 | 10.50 | -
https://www.amazon.co.uk/dp/B0895QT2YH | DC-DC voltage regulator | DC-DC 5A Buck Converter 4-38V to 1.25-36V Voltage Regulator | 1 | 12.99 | 0.00 | 12.99 | -
https://www.amazon.co.uk/dp/B08GKT11BW | 24V DC power supply | inShareplus 24V 20A 480W | 1 | 37.59 | 0.00 | 37.59 | -
https://www.amazon.co.uk/dp/B088D3FWR7 | Teensy 4.1 | Teensy 4.1 | 1 | 42.36 | 0.00 | 42.36 | -
- | - | Total shipping fees | 1 | 0 | 15.00 | 15.00 | -
3D-Printed Components
https://github.com/UpsidedownFalcon/IMU-Turntable/blob/main/build/CAD/3D%20Print%20Files/Base%201.3mf | Base 1 | Bambulab PLA Basic | 1 | - | - | - | 0.2mm layer; 0.2mm initial layer; 0.42mm line width; 2 walls; 15% infill; 50mm/s initial layer; 105mm/s initial layer fill; 200mm/s outer wall; 300mm/s inner wall; tree support; 10000mm/s2 normal acceleration; 220C nozzle temperature; 55C bed temperature
https://github.com/UpsidedownFalcon/IMU-Turntable/blob/main/build/CAD/3D%20Print%20Files/Base%202.3mf | Base 2 | Bambulab PLA Basic | 1 | - | - | - | 0.2mm layer; 0.2mm initial layer; 0.42mm line width; 2 walls; 15% infill; 50mm/s initial layer; 105mm/s initial layer fill; 200mm/s outer wall; 300mm/s inner wall; tree support; 10000mm/s2 normal acceleration; 220C nozzle temperature; 55C bed temperature
https://github.com/UpsidedownFalcon/IMU-Turntable/blob/main/build/CAD/3D%20Print%20Files/Base%203.3mf | Base 3 | Bambulab PLA Basic | 1 | - | - | - | 0.2mm layer; 0.2mm initial layer; 0.42mm line width; 2 walls; 15% infill; 50mm/s initial layer; 105mm/s initial layer fill; 200mm/s outer wall; 300mm/s inner wall; tree support; 10000mm/s2 normal acceleration; 220C nozzle temperature; 55C bed temperature
https://github.com/UpsidedownFalcon/IMU-Turntable/blob/main/build/CAD/3D%20Print%20Files/Base%204.3mf | Base 4 | Bambulab PLA Basic | 1 | - | - | - | 0.2mm layer; 0.2mm initial layer; 0.42mm line width; 2 walls; 15% infill; 50mm/s initial layer; 105mm/s initial layer fill; 200mm/s outer wall; 300mm/s inner wall; tree support; 10000mm/s2 normal acceleration; 220C nozzle temperature; 55C bed temperature
https://github.com/UpsidedownFalcon/IMU-Turntable/blob/main/build/CAD/3D%20Print%20Files/Base%20Post%201.3mf | Base Post 1 | Bambulab PLA Basic | 1 | - | - | - | 0.2mm layer; 0.2mm initial layer; 0.42mm line width; 2 walls; 15% infill; 50mm/s initial layer; 105mm/s initial layer fill; 200mm/s outer wall; 300mm/s inner wall; tree support; 10000mm/s2 normal acceleration; 220C nozzle temperature; 55C bed temperature
https://github.com/UpsidedownFalcon/IMU-Turntable/blob/main/build/CAD/3D%20Print%20Files/Base%20Post%202.3mf | Base Post 2 | Bambulab PLA Basic | 1 | - | - | - | 0.2mm layer; 0.2mm initial layer; 0.42mm line width; 2 walls; 15% infill; 50mm/s initial layer; 105mm/s initial layer fill; 200mm/s outer wall; 300mm/s inner wall; tree support; 10000mm/s2 normal acceleration; 220C nozzle temperature; 55C bed temperature
https://github.com/UpsidedownFalcon/IMU-Turntable/blob/main/build/CAD/3D%20Print%20Files/Base%20Post%203.3mf | Base Post 3 | Bambulab PLA Basic | 1 | - | - | - | 0.2mm layer; 0.2mm initial layer; 0.42mm line width; 2 walls; 15% infill; 50mm/s initial layer; 105mm/s initial layer fill; 200mm/s outer wall; 300mm/s inner wall; tree support; 10000mm/s2 normal acceleration; 220C nozzle temperature; 55C bed temperature
https://github.com/UpsidedownFalcon/IMU-Turntable/blob/main/build/CAD/3D%20Print%20Files/Base%20Post%204.3mf | Base Post 4 | Bambulab PLA Basic | 1 | - | - | - | 0.2mm layer; 0.2mm initial layer; 0.42mm line width; 2 walls; 15% infill; 50mm/s initial layer; 105mm/s initial layer fill; 200mm/s outer wall; 300mm/s inner wall; tree support; 10000mm/s2 normal acceleration; 220C nozzle temperature; 55C bed temperature
https://github.com/UpsidedownFalcon/IMU-Turntable/blob/main/build/CAD/3D%20Print%20Files/Base%20Rotary%20Encoder%20Bracket.3mf | Base Rotary Encoder Bracket | Bambulab PLA Basic | 1 | - | - | - | 0.2mm layer; 0.2mm initial layer; 0.42mm line width; 2 walls; 15% infill; 50mm/s initial layer; 105mm/s initial layer fill; 200mm/s outer wall; 300mm/s inner wall; tree support; 10000mm/s2 normal acceleration; 220C nozzle temperature; 55C bed temperature
https://github.com/UpsidedownFalcon/IMU-Turntable/blob/main/build/CAD/3D%20Print%20Files/Base%20Stepper%20Bracket.3mf | Base Stepper Bracket | Bambulab PLA Basic | 1 | - | - | - | 0.2mm layer; 0.2mm initial layer; 0.42mm line width; 2 walls; 15% infill; 50mm/s initial layer; 105mm/s initial layer fill; 200mm/s outer wall; 300mm/s inner wall; tree support; 10000mm/s2 normal acceleration; 220C nozzle temperature; 55C bed temperature
https://github.com/UpsidedownFalcon/IMU-Turntable/blob/main/build/CAD/3D%20Print%20Files/IMU%20Carriage_Bottom.3mf | IMU Carriage_Bottom | Bambulab PLA Basic | 1 | - | - | - | 0.2mm layer; 0.2mm initial layer; 0.42mm line width; 2 walls; 15% infill; 50mm/s initial layer; 105mm/s initial layer fill; 200mm/s outer wall; 300mm/s inner wall; tree support; 10000mm/s2 normal acceleration; 220C nozzle temperature; 55C bed temperature
https://github.com/UpsidedownFalcon/IMU-Turntable/blob/main/build/CAD/3D%20Print%20Files/IMU%20Carriage_Top.3mf | IMU Carriage_Top | Bambulab PLA Basic | 1 | - | - | - | 0.2mm layer; 0.2mm initial layer; 0.42mm line width; 2 walls; 15% infill; 50mm/s initial layer; 105mm/s initial layer fill; 200mm/s outer wall; 300mm/s inner wall; tree support; 10000mm/s2 normal acceleration; 220C nozzle temperature; 55C bed temperature
https://github.com/UpsidedownFalcon/IMU-Turntable/blob/main/build/CAD/3D%20Print%20Files/TPU%20Universal%20Mount.3mf | TPU Universal Mount | Bambulab 85A TPU | 4 | 0.29 | 0.00 | 1.16 | 0.2mm layer height; 0.2mm initial layer height; 0.42mm line width; 2 walls; 15% gyroid infill; 10mm/s initial layer; 10mm/s initial layer fill; 25mm/s outer wall; 30mm/s inner wall; 25mm/s infill; tree support; 6000mm/s² normal acceleration; 220°C nozzle temperature; 55°C bed temperature; retraction 1.0mm @ 25mm/s; travel 80mm/s; fan 40% after 2 layers; combing on; coasting off; Z-hop 0.2mm
https://github.com/UpsidedownFalcon/IMU-Turntable/blob/main/build/CAD/3D%20Print%20Files/X%20Bobbin.3mf | X Bobbin | Bambulab PLA Basic | 1 | - | - | - | 0.2mm layer; 0.2mm initial layer; 0.42mm line width; 2 walls; 15% infill; 50mm/s initial layer; 105mm/s initial layer fill; 200mm/s outer wall; 300mm/s inner wall; tree support; 10000mm/s2 normal acceleration; 220C nozzle temperature; 55C bed temperature
https://github.com/UpsidedownFalcon/IMU-Turntable/blob/main/build/CAD/3D%20Print%20Files/X%20Bracket.3mf | X Bracket | Bambulab PLA Basic | 1 | - | - | - | 0.2mm layer; 0.2mm initial layer; 0.42mm line width; 2 walls; 15% infill; 50mm/s initial layer; 105mm/s initial layer fill; 200mm/s outer wall; 300mm/s inner wall; tree support; 10000mm/s2 normal acceleration; 220C nozzle temperature; 55C bed temperature
https://github.com/UpsidedownFalcon/IMU-Turntable/blob/main/build/CAD/3D%20Print%20Files/Y%20Bobbin.3mf | Y Bobbin | Bambulab PLA Basic | 1 | - | - | - | 0.2mm layer; 0.2mm initial layer; 0.42mm line width; 2 walls; 15% infill; 50mm/s initial layer; 105mm/s initial layer fill; 200mm/s outer wall; 300mm/s inner wall; tree support; 10000mm/s2 normal acceleration; 220C nozzle temperature; 55C bed temperature
https://github.com/UpsidedownFalcon/IMU-Turntable/blob/main/build/CAD/3D%20Print%20Files/Y%20Bracket%201.3mf | Y Bracket 1 | Bambulab PLA Basic | 1 | - | - | - | 0.2mm layer; 0.2mm initial layer; 0.42mm line width; 2 walls; 15% infill; 50mm/s initial layer; 105mm/s initial layer fill; 200mm/s outer wall; 300mm/s inner wall; tree support; 10000mm/s2 normal acceleration; 220C nozzle temperature; 55C bed temperature
https://github.com/UpsidedownFalcon/IMU-Turntable/blob/main/build/CAD/3D%20Print%20Files/Y%20Bracket%202.3mf | Y Bracket 2 | Bambulab PLA Basic | 1 | - | - | - | 0.2mm layer; 0.2mm initial layer; 0.42mm line width; 2 walls; 15% infill; 50mm/s initial layer; 105mm/s initial layer fill; 200mm/s outer wall; 300mm/s inner wall; tree support; 10000mm/s2 normal acceleration; 220C nozzle temperature; 55C bed temperature
https://github.com/UpsidedownFalcon/IMU-Turntable/blob/main/build/CAD/3D%20Print%20Files/Z%20Plate.3mf | Z Plate | Bambulab PLA Basic | 1 | - | - | - | 0.2mm layer; 0.2mm initial layer; 0.42mm line width; 2 walls; 15% infill; 50mm/s initial layer; 105mm/s initial layer fill; 200mm/s outer wall; 300mm/s inner wall; tree support; 10000mm/s2 normal acceleration; 220C nozzle temperature; 55C bed temperature
- | Cost of all PLA parts from Bambu Studio slicer | - | 1 | 16.13 | 0.00 | 16.13

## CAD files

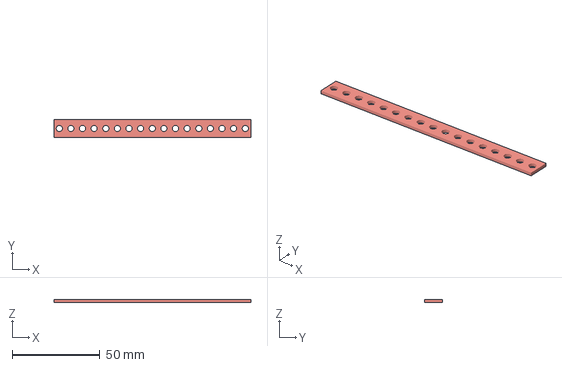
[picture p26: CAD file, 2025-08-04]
build/CAD/3D Print Files/TPU Universal Mount.3mf
112.0 x 10.1 x 1.50 mm

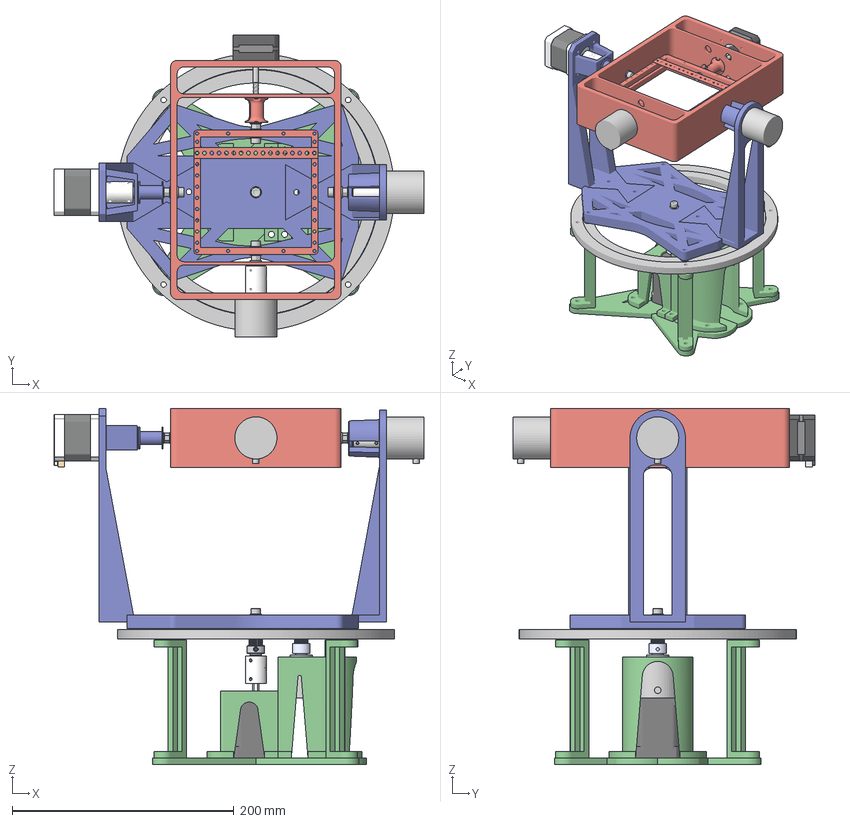
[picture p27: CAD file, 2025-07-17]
build/CAD/High Tech Fidget Spinner v37.3mf
333.9 x 272.7 x 321.4 mm
Base 1
Base 2
Base 3
Base 4
Base Post 1
Base Post 2
Base Post 3
Base Post 4
Base Rotary Encoder Bracket
Base Stepper Bracket
Holder
IMU Carriage_Bottom
IMU Carriage_Top
X Bobbin (1)
X Bobbin
X Bracket
Y Bobbin
Y Bracket 1
Y Bracket 2
Z Plate

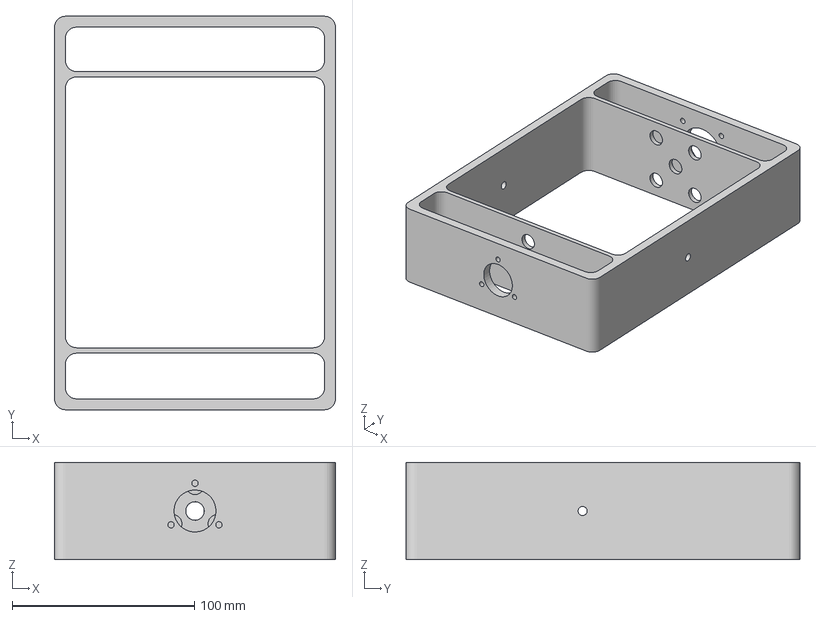
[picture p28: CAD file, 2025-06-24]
build/CAD/3D Print Files/X Bracket.3mf
154.0 x 215.7 x 53.3 mm

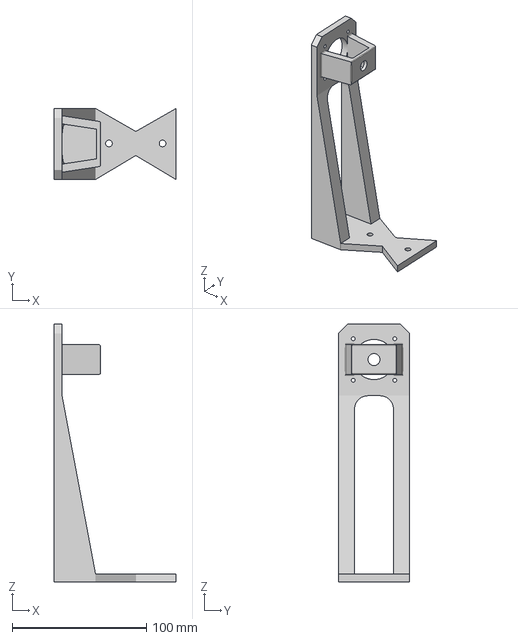
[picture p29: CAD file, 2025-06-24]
build/CAD/3D Print Files/Y Bracket 1.3mf
91.0 x 53.0 x 192.5 mm

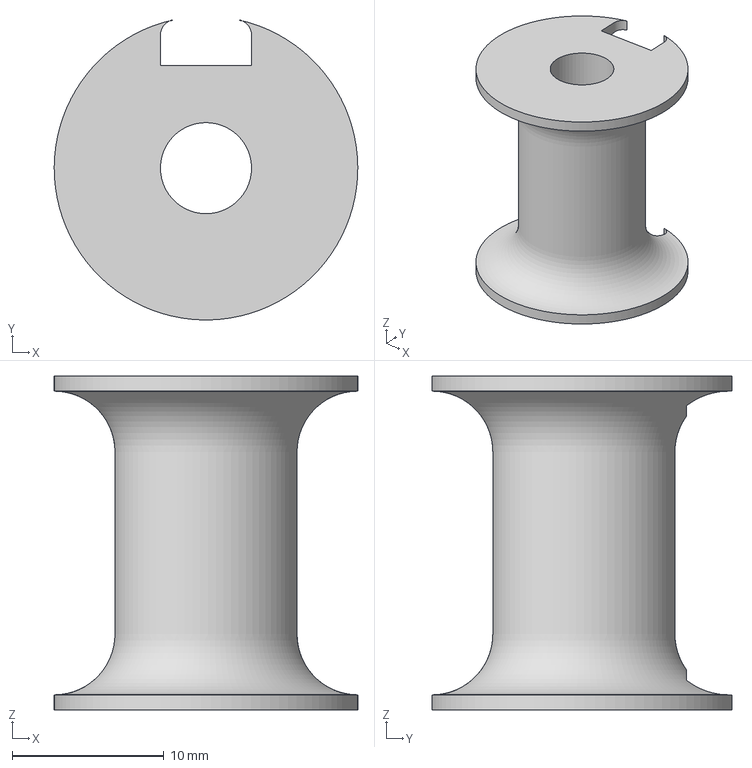
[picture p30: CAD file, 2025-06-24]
build/CAD/3D Print Files/X Bobbin.3mf
20.0 x 19.7 x 22.0 mm

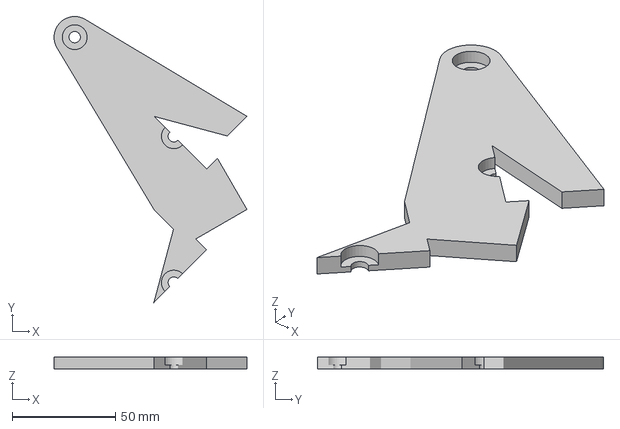
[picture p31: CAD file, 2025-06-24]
build/CAD/3D Print Files/Base 4.3mf
93.3 x 138.3 x 6.00 mm

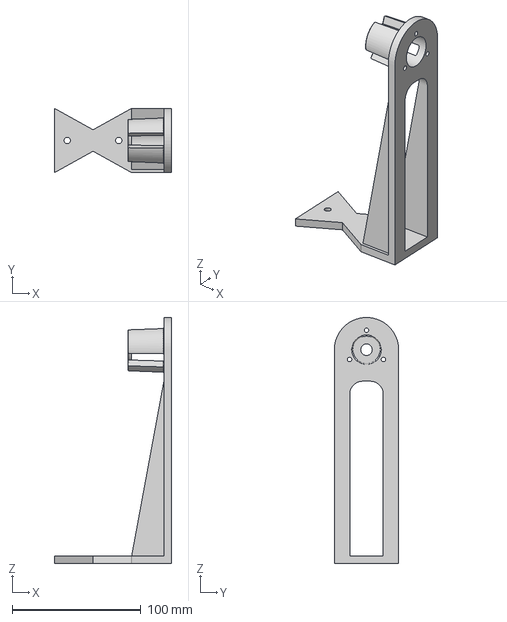
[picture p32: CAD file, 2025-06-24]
build/CAD/3D Print Files/Y Bracket 2.3mf
91.0 x 50.0 x 191.0 mm

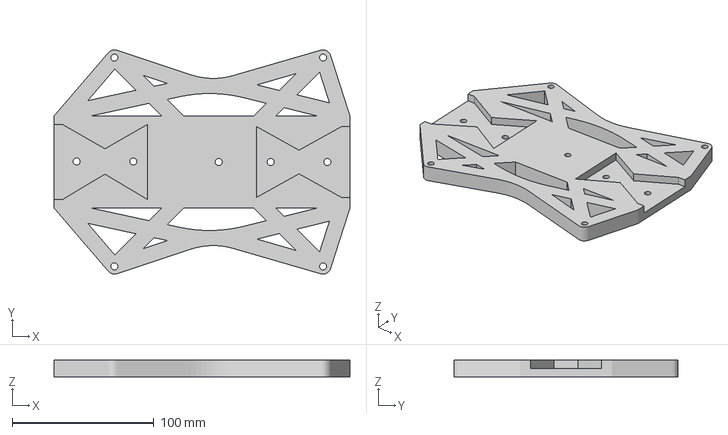
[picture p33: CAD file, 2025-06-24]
build/CAD/3D Print Files/Z Plate.3mf
209.1 x 158.4 x 12.0 mm

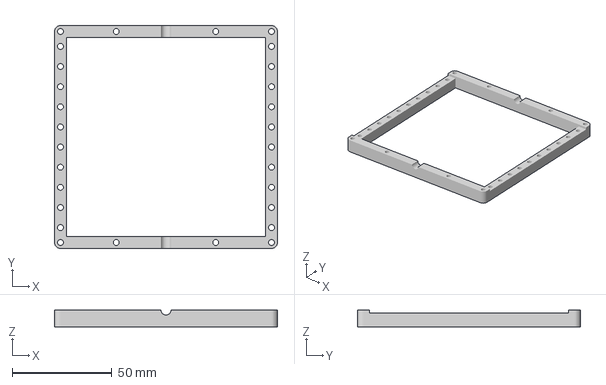
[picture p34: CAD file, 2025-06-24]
build/CAD/3D Print Files/IMU Carriage_Bottom.3mf
112.0 x 112.0 x 8.50 mm

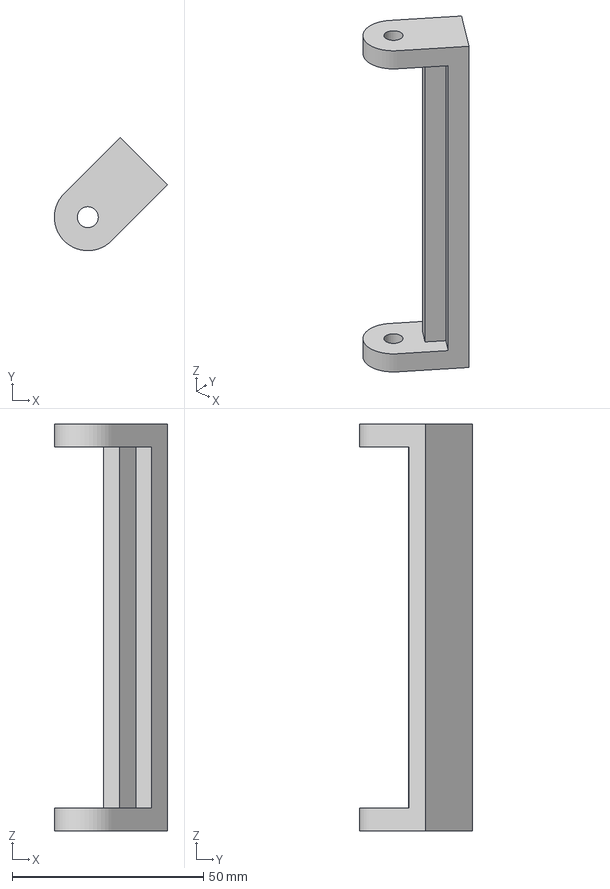
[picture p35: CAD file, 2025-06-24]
build/CAD/3D Print Files/Base Post 1.3mf
29.6 x 29.6 x 106.3 mm

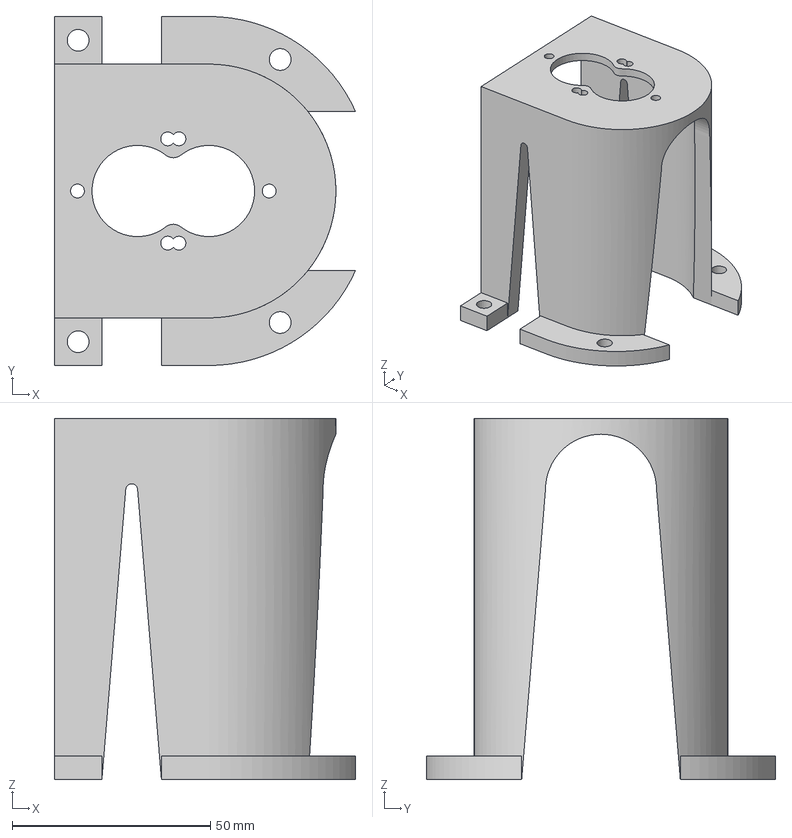
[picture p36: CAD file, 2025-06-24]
build/CAD/3D Print Files/Base Rotary Encoder Bracket.3mf
76.0 x 88.0 x 91.1 mm

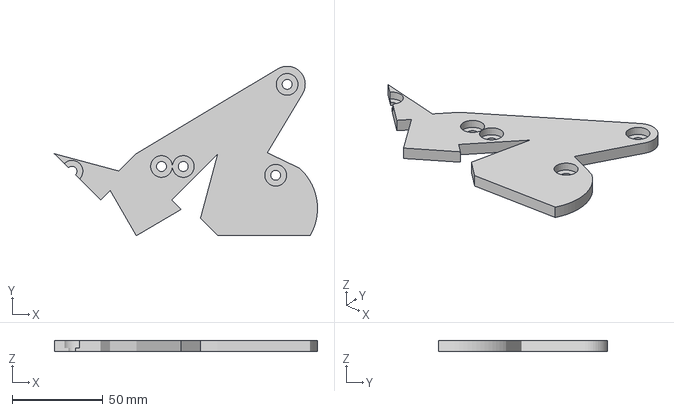
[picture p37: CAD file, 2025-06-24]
build/CAD/3D Print Files/Base 3.3mf
145.0 x 93.4 x 6.00 mm

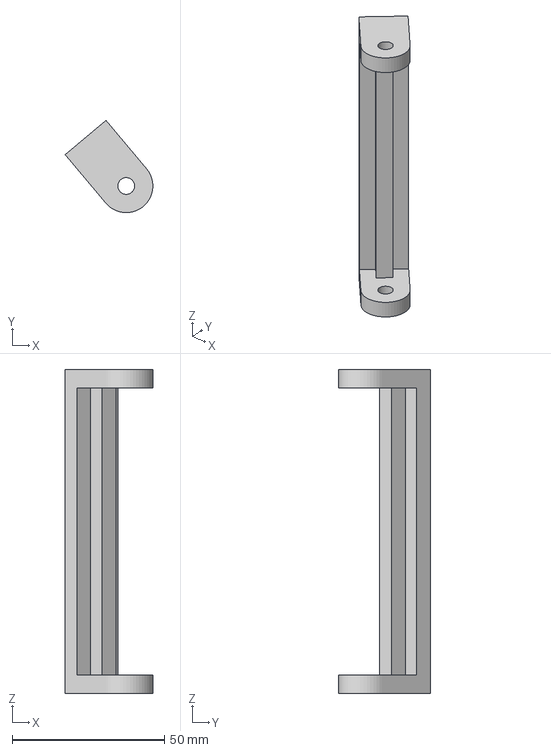
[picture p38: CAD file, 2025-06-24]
build/CAD/3D Print Files/Base Post 4.3mf
28.8 x 30.3 x 106.3 mm

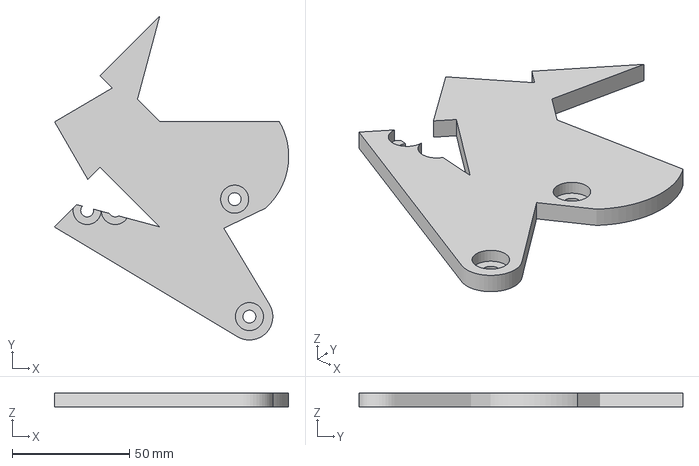
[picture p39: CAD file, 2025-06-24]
build/CAD/3D Print Files/Base 2.3mf
100.0 x 138.3 x 6.00 mm

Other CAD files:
build/CAD/3D Print Files/Base 1.3mf
build/CAD/3D Print Files/IMU Carriage_Top.3mf
build/CAD/3D Print Files/Base Post 3.3mf
build/CAD/3D Print Files/Base Post 2.3mf
build/CAD/3D Print Files/Base Stepper Bracket.3mf
build/CAD/3D Print Files/Y Bobbin.3mf

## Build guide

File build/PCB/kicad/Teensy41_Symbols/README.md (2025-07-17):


Donate using Liberapay (https://liberapay.com/xengi/donate)

Teensy symbol library for KiCAD
=======================================

This repo includes KiCAD symbols for the following Teensy versions:

  - Teensy 1.0
  - Teensy++ 1.0
  - Teensy 2.0
  - Teensy++ 2.0
  - Teensy 3.0
  - Teensy 3.1
  - Teensy 3.2
  - Teensy 3.5
  - Teensy 3.6
  - Teensy 4.0
  - Teensy 4.1
  - Teensy LC

There are two symbols for Teensy 3.5/3.6: one that includes the through-hole connections on Teensy and one that adds all of the SMT connections on the bottom of the Teensy.

For footprints look here: https://github.com/XenGi/teensy.pretty

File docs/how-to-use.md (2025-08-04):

# How to Use the High-Tech Fidget Spinner 

Congratulations! If you have made it this far, you hopefully have a (working) 3-DoF IMU turntable! Here's how to use it: 

1) Insert a MicroSD card into your device - make sure it has **nothing saved onto it** 

2) Within your empty MicroSD card, create an **empty folder** called ```traj``` 

3) Open the webapp UI Python code at [```src/webapp/webapp.py```](/src/webapp/webapp.py) 

4) Replace line 292, ```sd_mount = r"D:\traj"```, with the path to ```traj``` on your MicroSD card 

5) Run the Python script and navigate to the IP address printed in the termainal 

6) You will see an UI which looks like this:

009_GUI

The UI transitions between the following stages: 

008_Webapp architecture

Through the UI, you can: 
- Change your stepper motor parameters 
- Enter a trajectory for the X, Y and Z axes as piecewise functions 
- Once a trajectory has been entered for **all three** axes, save them onto the MicroSD card 

7) Once trajectories have been saved onto the MicroSD card, remove it from your computer 

8) Navigate to [```/src/firmware/main/main.ino```](/src/firmware/main/main.ino) and modify lines 24 and 25 such that ```STEPS_PER_REV``` and ```MICROSTEPS``` match your stepper motor parameters and stepper driver configuration. Then **upload the firmware** to the controller board 

9) With the controller board **powered off**, insert the MicroSD card into the Teensy 4.1 

10) **First** turn on the +24V DC supply for the stepper motors 

11) **Second**, turn on the +5V DC supply for the Teensy 4.1

12) Et voilà! 

## Bespoke use 

- You can use the universal TPU mounts to attach your own IMU device to the High-Tech Fidget Spinner 

- You can modify [```/src/firmware/main/main.ino```](/src/firmware/main/main.ino) to include bespoke code to synchronously log data from your IMU device to the MicroSD card

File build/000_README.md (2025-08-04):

# ```/build/``` 

This directory contains files and instructions to build the mechanical and electronic parts of the High-Tech Fidget Spinner. 

```
├── CAD/                       # Contains all of the required CAD files 
├── PCB/                       # Contains all of the required PCB files 
├── assembly-guide.md          # Assembly guide
├── BoM.csv                     # Bill of materials 
└── README.md
```

## ```/build/CAD/``` 
- [```./3D Print Files/```](/build/CAD/3D%20Print%20Files/) contains **.3mf** files for 3D-printing 
- Contains *.3mf*, *.f3z*, *.step* and *.stl* **assembly** files for the project
    - These can be opened in your preferred CAD software for modification 

## ```/build/PCB/``` 
- [```./GERBER/```](/build/PCB/GERBER/) contains GERBER files for PCB manufacture 
    - [```./GERBER/Drill Files```](/build/PCB/GERBER/Drill%20Files/) contains drill files for PCB manufacture 
- [```./kicad/```](/build/PCB/kicad/) contains KiCad project files <--- OPEN THE PROJECT FILE WITH **KICAD 9.0** 
- [```./schematic.pdf```](/build/PCB/schmeatic.pdf) contains the schematic for the electronics 

## ```/build/assembly-guide.md```
This document explains how to complete the 

- mechanical assembly 
- electronic assembly 

for the High-Tech fidget spinner. 

## ```/build/BoM.csv``` 
This document is the bill of materials for High-Tech Fidget Spinner. 

## Start building! 

0) Familiarise yourself with [```/build/assembly-guide.md```](/build/assembly-guide.md) 
1) Source the components from [```/build/BoM.csv```](/build/BoM.csv) 
2) Follow the instructions in [```/build/assembly-guide.md```](/build/assembly-guide.md) 
3) Test and tweak!

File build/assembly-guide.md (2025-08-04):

# Assembly Guide 

To have a functioning High-Tech Fidget Spinner, there are three high-level steps: 
1) Mechanical assembly 
2) Electronic assembly 
3) Flashing firmware 

Completing these three steps may take anywhere between **2 - 4+ hours**. Before starting, please make sure you have all of the materials from [```/build/BoM.csv```](/build/BoM.csv) and the appropriate tools. 

All of the 3D print files should be printed. Materials and print settings are outlined in [```/build/BoM.csv```](/build/BoM.csv). 

Let's begin! 

## Mechanical assembly 

The mechanical assembly is split into the following assemblies: 
- Z-frame subassembly 
- Y-frame subassembly 
- X-frame subassembly 

### Z-frame subassembly 
1) Assemble the 4 base pieces together like a jigsaw puzzle! 



2) Attach the Nema 17 42-60 to the Base Stepper Bracket 



3) Attach the E38S6G5-600B-G24 rotary encoder to the Base Rotary Encoder Bracket 



4) Mount the Base Stepper Bracket and Base Rotary Encoder Bracket to the base 



5) Attach the 4 Base Posts to the corners of the base 



6) Secure the turntable bearing on top of the Base Posts 



7) Fix a shaft coupler to the shaft of the Nema 17 42-60 stepper motor. Fix a GT20 pulley around the shaft of t he E38S6G5-600B-G24 rotary encoder. Loop a 122mm GT20 timing belt around the pulley 



### Y-frame subassembly 
1) Slot the Y Bracket 1 and Y Bracket 2 into the Z Plate 



2) Add M5 screws and secure Y Bracket 1 and Y Bracket 2 with washers and nuts. Add M5 screws in the centre and around the edges of the Z Plate to fix it to the Z-frame subassembly 



3) Secure a GT20 timing pulley to the middle M5 screw of the Z Plate 



4) Mount the Y-frame subassembly on top of the Z-frame subassembly and fix using M5 nuts. 



### X-frame subassembly 
1) Screw the IMU Carriage_Top and IMU Carriage_Bottom together, with the semi-circles on them forming a complete hole. Run M5 screws with toothed washers through the holes 



2) Attach the IMU_Carriage to the X Bracket via the bearing inserts, while including the X Bobbin. Run M5 screws with toothed washers through the centre holes of the X Bracket 



3) Mount the Nema 17 42-23 and E38S6G5-600B-G24 rotary encoder respectively to the X Bracket and M5 screws of the IMU Carriage via the shaft couplings 



4) Attach the X Bracket to the Y-frame subassembly via the bearing inserts, while including the Y Bobbin 



5) Mount the Nema 17 42-38 and E38S6G5-600B-G24 rotary encoder to their respective Y Brackets 

 

6) Secure TPU Universal Mount to the IMU Carriage using M3 screws 

## Electronic assembly 
Connect the Teensy 4.1, TMC2209 drivers, stepper motors and rotary encoders as shown by the schematic below: 



All of the components can be connected together on a large breadboard: 



Or a custom PCB can be manufactured using the [GERBER](/build/PCB/GERBER/) files and the components can be soldered onto the PCB, following the board layout 

## Flashing firmware 
1) Download and ensure [```/src/firmware/main/main.ino/```](/src/firmware/main/main.ino) is placed inside a directory called ```/main/``` 
2) Open [```./main.ino/```](/src/firmware/main/main.ino) with the Arduino IDE 
3) Follow [this guide](https://www.pjrc.com/teensy/tutorial.html) to flash the code the a Teensy 4.1 

Well done! You now have a fully assembled High-Tech Fidget Spinner

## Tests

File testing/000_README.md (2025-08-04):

# ```/testing/```

The High-Tech Fidget Spinner was tested in a motion capture lab; IR reflectors were placed on all rotating frames and motion was captured using an Optitrak Prime X 22 system while each axis underwent a step trajectory individually. The stepped trajectory was a rotation from 0 deg to 90 deg in increments of 10 deg every 2 s - it is saved onto [```/testing/step.bin```](/testing/step.bin). The measured trajectory for the X, Y and Z axes are saved in [```/testing/Test_X.csv```](/testing/Test_X.csv), [```testing/Test_Y.csv```](/testing/Test_Y.csv) and [```/testing/Test_Z.csv```](/testing/Test_Z.csv) respectively. The mean deviation and resolution for each axis was analysed. 

```
├── error-plots.zip          # Error distribution plots 
├── Plot.py                  # Python script for statisical analysis 
├── README.md 
├── step.bin                 # True trajectory profile 
├── Test_X.csv               # Measured X trajectory profile 
├── Test_Y.csv               # Measured Y trajectory profile 
└── Test_Z.csv               # Measured Z trajectory profile 
``` 

## Error Statistics 
Data manually aligned in time and angle axes at the initial position 

### X-Axis 
- Trajectory starts at t = 5.8612s 
- 0 angular offset 
- Systematic error after t = 24.3331s: wires got stuck causing stepper to skip steps 
    => Hence data only analysed in the domain **t = [5.8612, 24.3331]s** to remove systematic error 

=> Deviation = 0.0277 +- 0.3226 deg

=> |Resolution| = 0.0461 +- 0.1142 deg 

X_error_figures

### Y-Axis
- Trajectory starts at t = 5.14s 
- -1.3 deg angular offset to account for a 0 error 
- No systematic errors 
    => Hence data analysed in the domain **t = [5.14, 43.14]s** 

=> Deviation = 0.0287 +- 0.8737 deg 

=> |Resolution| = 0.0469 +- 0.0983 deg 

Y_error_figures

### Z-Axis 
- Trajectory starts at t = 4.6083s 
- 0.3806 deg anguler offset to account for a 0 error 
- Systematic error after t = 30.6083s: wires got stuck causing stepper to skip steps 
    => Hence data only analysed in the domain **t = [4.6083, 30.6083]s** to remove systematic error 

=> Deviation = -0.1758 +- 0.1603 deg 

=> |Resolution| = 0.0457 +- 0.0586 deg 

Z_error_figures

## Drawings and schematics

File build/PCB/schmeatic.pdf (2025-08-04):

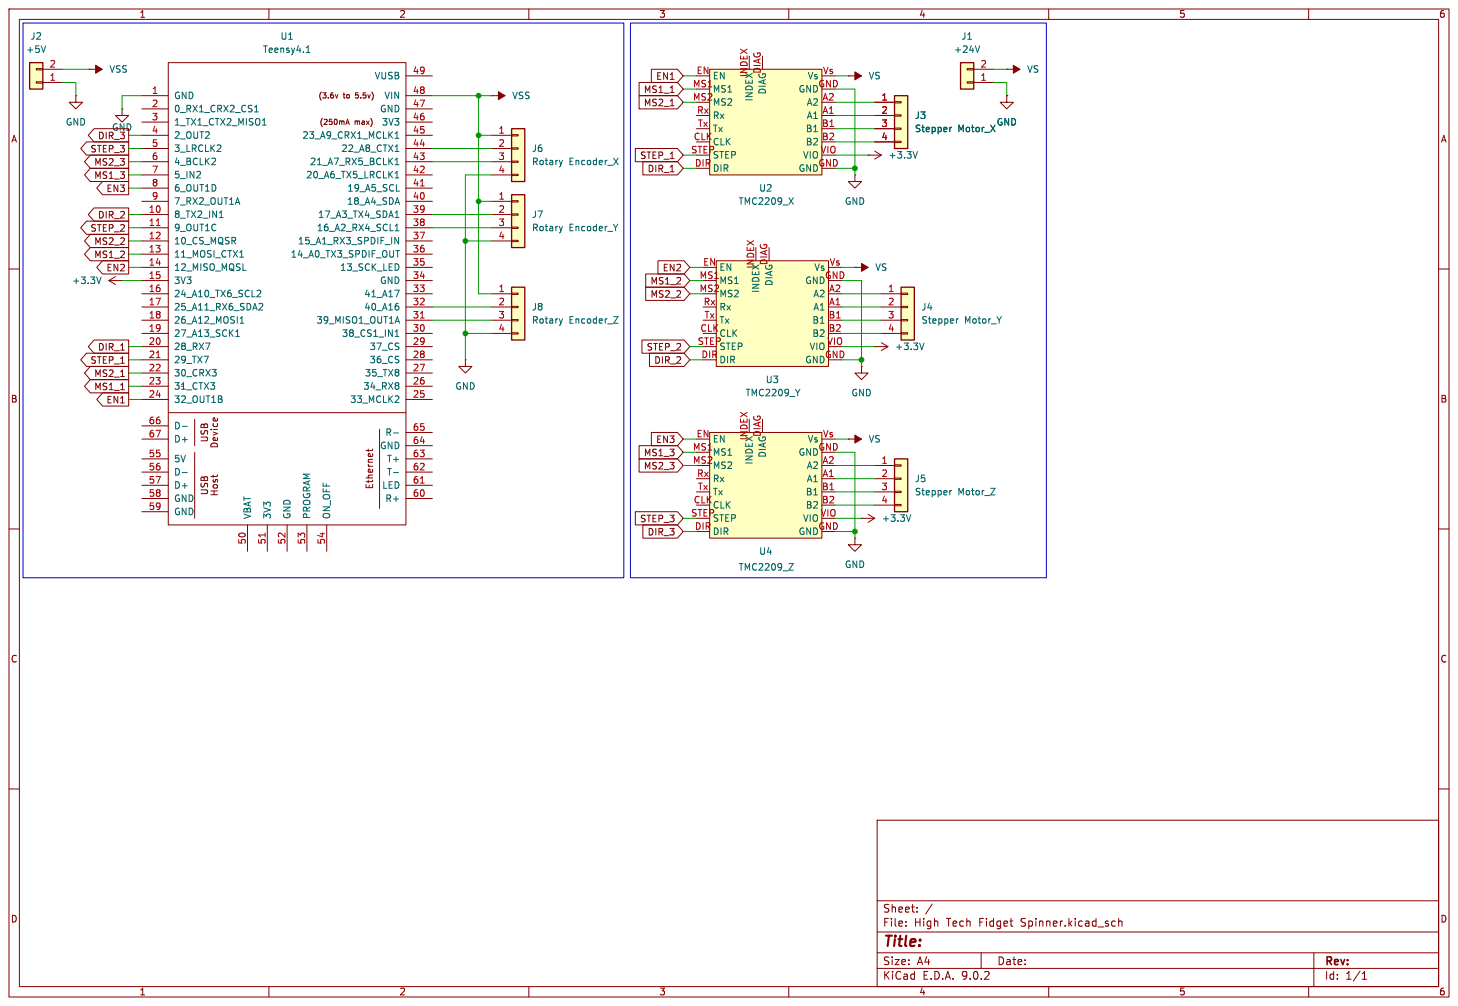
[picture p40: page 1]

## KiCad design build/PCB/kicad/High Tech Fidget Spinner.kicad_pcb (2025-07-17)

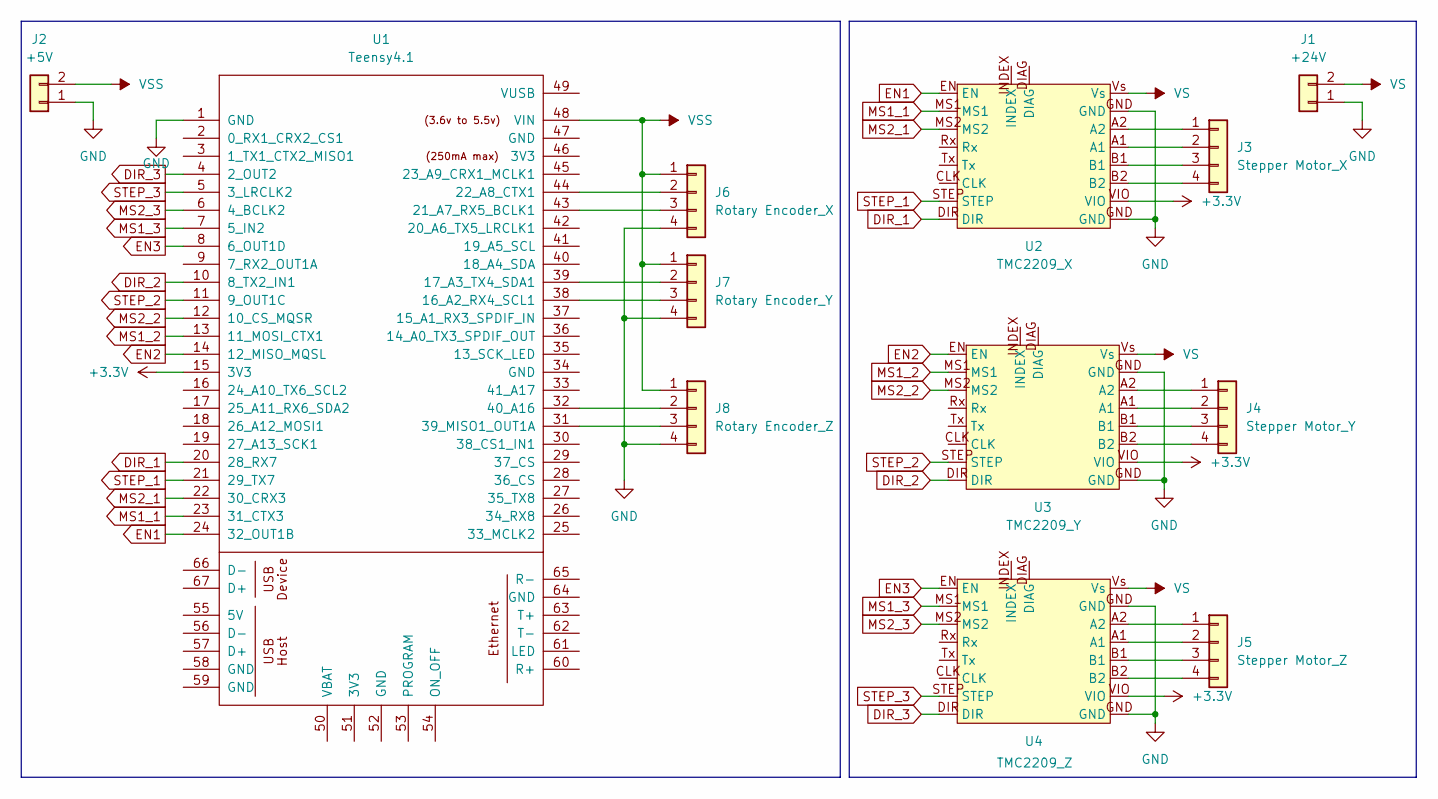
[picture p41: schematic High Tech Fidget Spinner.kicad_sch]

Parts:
J1: +24V; PinHeader_1x02_P2.54mm_Vertical
J2: +5V; PinHeader_1x02_P2.54mm_Vertical
J3: Stepper Motor_X; PinHeader_1x04_P2.54mm_Vertical
J4: Stepper Motor_Y; PinHeader_1x04_P2.54mm_Vertical
J5: Stepper Motor_Z; PinHeader_1x04_P2.54mm_Vertical
J6: Rotary Encoder_X; PinHeader_1x04_P2.54mm_Vertical
J7: Rotary Encoder_Y; PinHeader_1x04_P2.54mm_Vertical
J8: Rotary Encoder_Z; PinHeader_1x04_P2.54mm_Vertical
U1: Teensy4.1; Teensy41
U2: TMC2209_X; TMC2209
U3: TMC2209_Y; TMC2209
U4: TMC2209_Z; TMC2209

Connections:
+3.3V: U1.15 (3V3), U2.VIO, U3.VIO, U4.VIO
DIR_1: U1.20 (28_RX7), U2.DIR
DIR_2: U1.10 (8_TX2_IN1), U3.DIR
DIR_3: U1.4 (2_OUT2), U4.DIR
EN1: U1.24 (32_OUT1B), U2.EN
EN2: U1.14 (12_MISO_MQSL), U3.EN
EN3: U1.8 (6_OUT1D), U4.EN
GND: J1.1, J2.1, J6.4, J7.4, J8.4, U1.1 (GND), U2.GND, U3.GND, U4.GND
MS1_1: U1.23 (31_CTX3), U2.MS1
MS1_2: U1.13 (11_MOSI_CTX1), U3.MS1
MS1_3: U1.7 (5_IN2), U4.MS1
MS2_1: U1.22 (30_CRX3), U2.MS2
MS2_2: U1.12 (10_CS_MQSR), U3.MS2
MS2_3: U1.6 (4_BCLK2), U4.MS2
unnamed: J3.1, U2.A2
unnamed: J3.2, U2.A1
unnamed: J3.3, U2.B1
unnamed: J3.4, U2.B2
unnamed: J4.1, U3.A2
unnamed: J4.2, U3.A1
unnamed: J4.3, U3.B1
unnamed: J4.4, U3.B2
unnamed: J5.1, U4.A2
unnamed: J5.2, U4.A1
unnamed: J5.3, U4.B1
unnamed: J5.4, U4.B2
unnamed: J6.2, U1.44 (22_A8_CTX1)
unnamed: J6.3, U1.43 (21_A7_RX5_BCLK1)
unnamed: J7.2, U1.39 (17_A3_TX4_SDA1)
unnamed: J7.3, U1.38 (16_A2_RX4_SCL1)
unnamed: J8.2, U1.32 (40_A16)
unnamed: J8.3, U1.31 (39_MISO1_OUT1A)
STEP_1: U1.21 (29_TX7), U2.STEP
STEP_2: U1.11 (9_OUT1C), U3.STEP
STEP_3: U1.5 (3_LRCLK2), U4.STEP
VS: J1.2, U2.Vs, U3.Vs, U4.Vs
VSS: J2.2, J6.1, J7.1, J8.1, U1.48 (VIN)

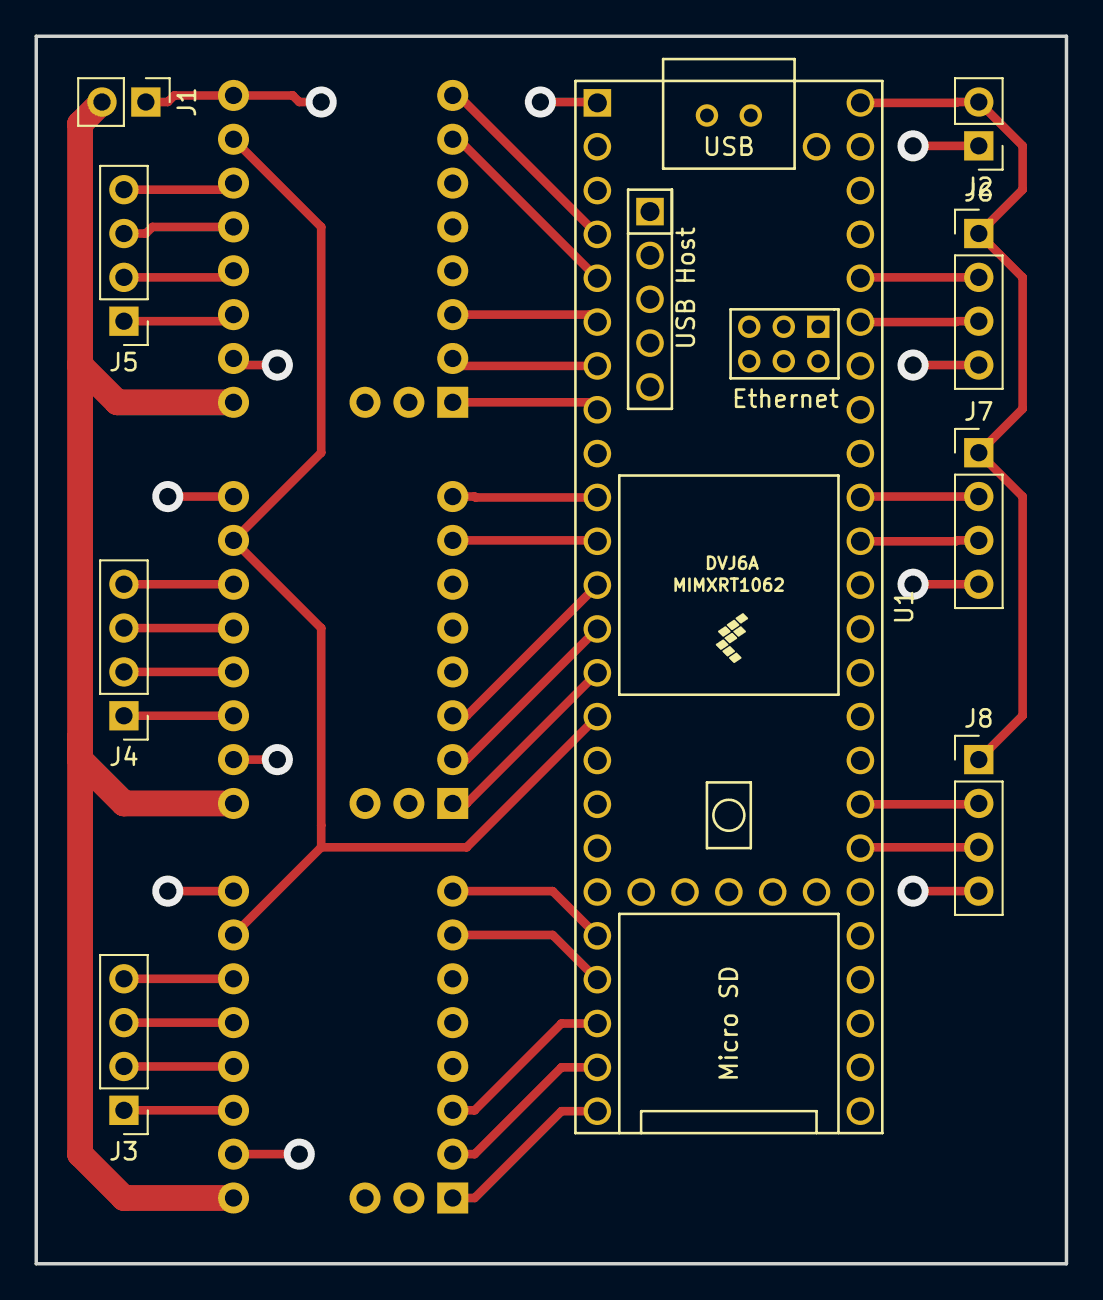
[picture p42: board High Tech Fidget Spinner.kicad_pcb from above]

Board: 2 copper layers, 59.7 x 71.1 mm, 12 parts (0 on the bottom side), 37 nets.

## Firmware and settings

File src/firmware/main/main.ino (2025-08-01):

#include <Arduino.h>
#include <SPI.h>
#include <SD.h>
#include <TMCStepper.h>

// Pin definitions for three drivers
#define EN1   2
#define STEP1 3

#define EN2   9
#define STEP2 6

#define EN3   30
#define STEP3 31

// UART interfaces
#define SERIAL1_PORT Serial1
#define SERIAL2_PORT Serial2
#define SERIAL3_PORT Serial7
#define DRIVER_ADDRESS 0b00

// Motor parameters
#define R_SENSE       0.11f
#define STEPS_PER_REV 200
#define MICROSTEPS    16
const float STEP_ANGLE   = 360.0f / STEPS_PER_REV;        // 1.8°
const float THETA_RES    = STEP_ANGLE / MICROSTEPS;       // 0.1125° per microstep 

// SD card
#define SD_CS BUILTIN_SDCARD
const char* TRAJ_DIR = "/traj";

// Driver objects
TMC2209Stepper driver1(&SERIAL1_PORT, R_SENSE, DRIVER_ADDRESS);
TMC2209Stepper driver2(&SERIAL2_PORT, R_SENSE, DRIVER_ADDRESS);
TMC2209Stepper driver3(&SERIAL3_PORT, R_SENSE, DRIVER_ADDRESS);

// Trajectory state per axis
struct TrajState {
  File      file;
  uint32_t  totalSamples;
  uint32_t  idx;            // next sample index (1..N-1)
  float     prevAngle;
  float     nextTime;       // seconds
  float     nextAngle;
  bool      done;
  int       stepPin;
  TMC2209Stepper* driver;
} traj[3];

// Start time reference
uint32_t startMicros;

// Helper to read a little-endian float from SD
float readFloatLE(File& f) {
  float v;
  f.read(&v, sizeof(v));
  return v;
}

void setup() {
  pinMode(13, OUTPUT);
  digitalWrite(13, HIGH);

  // Enable pins
  pinMode(EN1, OUTPUT); pinMode(EN2, OUTPUT); pinMode(EN3, OUTPUT);
  digitalWrite(EN1, LOW); digitalWrite(EN2, LOW); digitalWrite(EN3, LOW);

  // Step pins low
  pinMode(STEP1, OUTPUT); pinMode(STEP2, OUTPUT); pinMode(STEP3, OUTPUT);
  digitalWrite(STEP1, LOW); digitalWrite(STEP2, LOW); digitalWrite(STEP3, LOW);

  // Init UART drivers
  SERIAL1_PORT.begin(115200);
  driver1.begin(); driver1.toff(5); driver1.rms_current(2000);
  driver1.microsteps(MICROSTEPS); driver1.pwm_autoscale(true);

  SERIAL2_PORT.begin(115200);
  driver2.begin(); driver2.toff(5); driver2.rms_current(2000);
  driver2.microsteps(MICROSTEPS); driver2.pwm_autoscale(true);

  SERIAL3_PORT.begin(115200);
  driver3.begin(); driver3.toff(5); driver3.rms_current(2000);
  driver3.microsteps(MICROSTEPS); driver3.pwm_autoscale(true);

  // Mount SD
  if (!SD.begin(SD_CS)) {
    Serial.println("SD init failed");
    while (true) {}
  }
  // ensure folder
  if (!SD.exists(TRAJ_DIR)) {
    SD.mkdir(TRAJ_DIR);
  }

  // Open & prime trajectories
  const char* names[3] = { "X", "Y", "Z" };
  for (int i = 0; i < 3; i++) {
    traj[i].stepPin   = (i==0? STEP1 : (i==1? STEP2 : STEP3));
    traj[i].driver    = (i==0? &driver1 : (i==1? &driver2 : &driver3));
    traj[i].done      = false;
    String path = String(TRAJ_DIR) + "/" + names[i] + ".bin";
    traj[i].file = SD.open(path.c_str(), FILE_READ);
    if (!traj[i].file) {
      Serial.print("ERR: cannot open ");
      Serial.println(path);
      traj[i].done = true;
      continue;
    }
    // read sample count
    uint32_t N = 0;
    traj[i].file.read(&N, sizeof(N));
    traj[i].totalSamples = N;
    if (N < 2) {
      traj[i].done = true;
      continue;
    }
    // read first sample (t0, a0)
    float t0 = readFloatLE(traj[i].file);
    float a0 = readFloatLE(traj[i].file);
    traj[i].prevAngle = a0;
    // read second sample (t1, a1)
    traj[i].nextTime  = readFloatLE(traj[i].file);
    traj[i].nextAngle = readFloatLE(traj[i].file);
    traj[i].idx       = 1;
  }

  // record start timestamp
  startMicros = micros();
}

void loop() {
  uint32_t nowUs = micros();
  float    elapsedSec = (nowUs - startMicros) * 1e-6f;

  bool allDone = true;
  for (int i = 0; i < 3; i++) {
    if (traj[i].done) continue;
    allDone = false;

    // Time to apply this sample?
    if (elapsedSec >= traj[i].nextTime) {
      // compute angle delta
      float diff = traj[i].nextAngle - traj[i].prevAngle;
      if (fabs(diff) >= (THETA_RES * 0.5f)) {
        // set direction via UART driver
        bool dir = (diff >= 0);
        traj[i].driver->shaft(dir);

        // emit one microstep pulse
        digitalWrite(traj[i].stepPin, HIGH);
        delayMicroseconds(2);
        digitalWrite(traj[i].stepPin, LOW);
      }
      // advance
      traj[i].prevAngle = traj[i].nextAngle;
      traj[i].idx++;
      if (traj[i].idx < traj[i].totalSamples) {
        // read next (t,a)
        traj[i].nextTime  = readFloatLE(traj[i].file);
        traj[i].nextAngle = readFloatLE(traj[i].file);
      } else {
        // done with this axis
        traj[i].file.close();
        traj[i].done = true;
      }
    }
  }

  // optionally blink LED when all done
  if (allDone) {
    digitalWrite(13, !digitalRead(13));
    delay(200);
  }
}

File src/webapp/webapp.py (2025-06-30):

from flask import Flask, render_template, request, jsonify
import io, base64
import numpy as np
import matplotlib.pyplot as plt
import sympy as sp
import csv
import struct
import serial
from serial.tools import list_ports
import time
import os 

TRAJECTORIES = {
  'X': {'times': None, 'angles': None},
  'Y': {'times': None, 'angles': None},
  'Z': {'times': None, 'angles': None},
}

MIN_DT = 0.002

app = Flask(__name__)

def discretize_function(func, t_start, t_end, step_angle, microsteps, initial_samples=1000):
    """
    Discretize a continuous function for stepper motor control, robust to constant functions.
    Returns:
      times:  np.ndarray of timestamps
      angles: np.ndarray of angle values
      dt:      float, time step used
    """
    theta_res = step_angle / microsteps

    # 1) Initial sampling to estimate max velocity
    t_init     = np.linspace(t_start, t_end, initial_samples)
    theta_init = func(t_init)
    theta_arr  = np.array(theta_init, dtype=float)
    if theta_arr.ndim == 0:
        theta_arr = np.full(t_init.shape, theta_arr.item())
    elif theta_arr.shape != t_init.shape:
        theta_arr = np.broadcast_to(theta_arr, t_init.shape)

    dtheta_dt = np.diff(theta_arr) / np.diff(t_init)
    vmax      = np.max(np.abs(dtheta_dt)) if dtheta_dt.size else 0.0

    # 2) Compute dt so each microstep ≤ theta_res
    raw_dt = theta_res / vmax if vmax > 0 else (t_end - t_start)
    dt = max(raw_dt, MIN_DT)

    # 3) Final uniform sampling
    N     = int(np.ceil((t_end - t_start) / dt)) + 1
    times = np.linspace(t_start, t_end, N)
    angles = func(times)

    ang_arr = np.array(angles, dtype=float)
    if ang_arr.ndim == 0:
        ang_arr = np.full(times.shape, ang_arr.item())
    elif ang_arr.shape != times.shape:
        ang_arr = np.broadcast_to(ang_arr, times.shape)

    return times, ang_arr, dt

def discretize_all_segments(funcs, step_angle, microsteps):
    """
    funcs: list of (f_callable, t0, t1)
    Returns a single (times, angles) trajectory by concatenating segments.
    """
    all_times = []
    all_angles = []

    for f, t0, t1 in funcs:
        seg_t, seg_ang, _ = discretize_function(f, t0, t1, step_angle, microsteps)
        if all_times:  # drop duplicate boundary
            seg_t   = seg_t[1:]
            seg_ang = seg_ang[1:]
        all_times.append(seg_t)
        all_angles.append(seg_ang)

    if not all_times:
        return np.array([]), np.array([])

    return np.concatenate(all_times), np.concatenate(all_angles)

@app.route("/")
def index():
    return render_template("index.html")

@app.route("/plot", methods=["POST"])
def plot():
    data  = request.get_json()
    items = data.get("functions", [])
    if not items:
        return jsonify({"error":"No functions provided"}), 400

    x = sp.symbols('x')
    parsed = []
    gmin = gmax = None

    for idx, it in enumerate(items, start=1):
        expr_str = it.get("function","").strip()
        dom_str  = it.get("domain","").strip()
        if not expr_str or not dom_str:
            continue
        try:
            a,b = map(float, dom_str.split(","))
        except:
            return jsonify({"error":f"Invalid domain on row {idx}. Use start,end"}),400
        gmin = a if gmin is None or a<gmin else gmin
        gmax = b if gmax is None or b>gmax else gmax
        try:
            expr = sp.sympify(expr_str)
            f    = sp.lambdify(x, expr, "numpy")
        except:
            return jsonify({"error":f"Invalid expression on row {idx}: {expr_str}"}),400
        parsed.append((expr_str,f,a,b))

    if not parsed:
        return jsonify({"error":"No valid function/domain pairs found"}),400

    xs = np.linspace(gmin, gmax, 1000)
    fig, ax = plt.subplots()
    for expr_str,f,a,b in parsed:
        mask = (xs>=a)&(xs<=b)
        if not mask.any(): continue
        ys = f(xs[mask])
        ys = np.array(ys, dtype=float)
        if ys.ndim==0:
            ys = np.full(mask.sum(), ys.item())
        elif ys.shape!=(mask.sum(),):
            ys = np.broadcast_to(ys, (mask.sum(),))
        ax.plot(xs[mask], ys, label=f"y = {expr_str}")
    ax.set_xlim(gmin, gmax)
    ax.set_xlabel("x"); ax.set_ylabel("y"); ax.grid(True); ax.legend(fontsize="small")
    buf = io.BytesIO()
    fig.savefig(buf, format="png", bbox_inches="tight"); plt.close(fig)
    buf.seek(0)
    return jsonify({"img": base64.b64encode(buf.read()).decode('ascii')})

@app.route("/discretize", methods=["POST"])
def discretize():
    data       = request.get_json()
    motor      = data.get("motor")     # e.g. "X" or "Y" or "Z"
    items      = data.get("functions", [])
    step_angle = float(data.get("step_angle", 1.8))
    microsteps = int(data.get("microsteps", 16))
    if not items:
        return jsonify({"error":"No functions provided"}),400

    x = sp.symbols('x')
    funcs = []
    for idx,it in enumerate(items, start=1):
        fn = it.get("function","").strip()
        dm = it.get("domain","").strip()
        if not fn or not dm: continue
        try:
            t0,t1 = map(float, dm.split(","))
        except:
            return jsonify({"error":f"Invalid domain on row {idx}. Use start,end"}),400
        try:
            expr = sp.sympify(fn)
            f    = sp.lambdify(x, expr, "numpy")
        except:
            return jsonify({"error":f"Invalid expression on row {idx}: {fn}"}),400
        funcs.append((f,t0,t1))

    if not funcs:
        return jsonify({"error":"No valid segments to discretize"}),400

    times, angles = discretize_all_segments(funcs, step_angle, microsteps)

    if motor in TRAJECTORIES:
        TRAJECTORIES[motor]['times']  = times
        TRAJECTORIES[motor]['angles'] = angles
        print(motor)
        # if motor == 'Z':
        #     save_all_trajectories_csv()

    return jsonify({"times":times.tolist(), "angles":angles.tolist()})
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

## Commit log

2025-06-03 stepper iteration
2025-06-03 stepper initial ideas
2025-06-05 Stepper data
2025-06-27 1 stepper working
2025-06-30 trajectory planning
    [angles.csv, times.csv]
2025-07-17 Paper submission
    [Base 1.3mf, Base 2.3mf, Base 3.3mf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]
2025-08-04 Updat assembly-guide
2025-08-04 added tpu mount
    [TPU Universal Mount.3mf]
2025-08-04 Added BoM
    [BoM.csv]
